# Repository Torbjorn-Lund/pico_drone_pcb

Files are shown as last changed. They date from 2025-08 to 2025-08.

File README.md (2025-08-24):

# pico_drone_pcb





Custom PCB for a Raspberry Pi Pico–powered drone.  

This board integrates the core electronics needed to run a quadcopter, with power regulation, sensor connectors, and interfaces for ESCs and other peripherals.

The corresponding code, written in c can be found [here](https://github.com/Torbjorn-Lund/pico_drone_project)

## Features
- Designed for **Raspberry Pi Pico 2**  
- Power regulation:
  - Buck converter supporting up to **18 V input**
  - **TVS diode protection** limiting input voltage to ~10 V  
  - Optimized for **2S LiPo batteries (≈7.4 V nominal, 8.4 V fully charged)**  
- Breakouts for:
  - ESCs (dshot)
  - IMU (ICM-20948)  
  - Barometer (BMP280)  
  - GPS (NEO-M8N)  
  - Time-of-flight sensor (VL53L1X)  

## Images
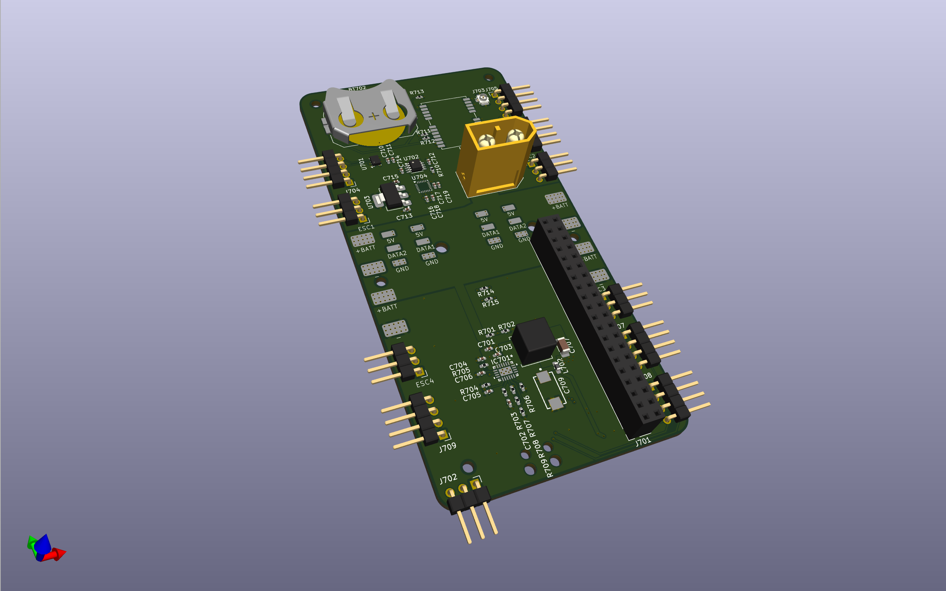
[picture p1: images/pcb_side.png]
PCB image Optional Title

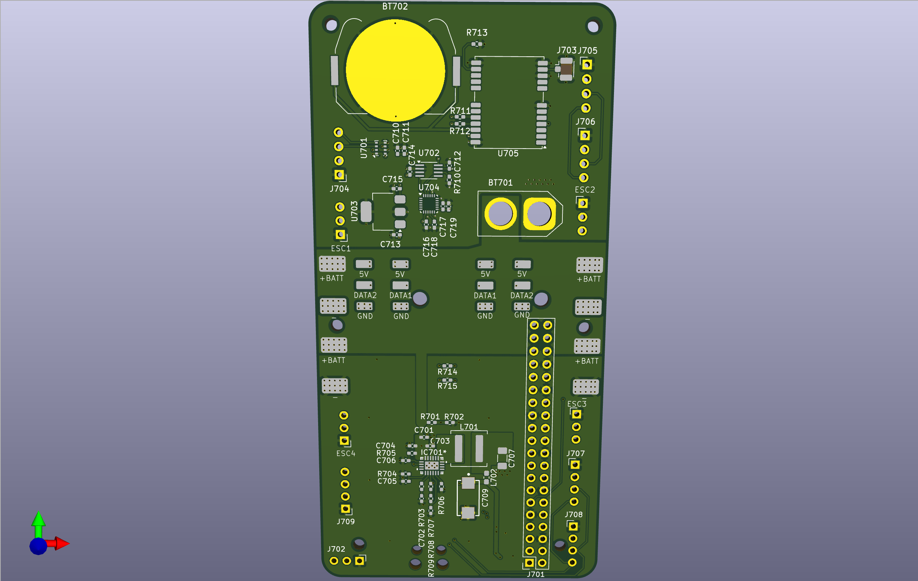
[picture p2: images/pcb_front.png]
PCB image Optional Title

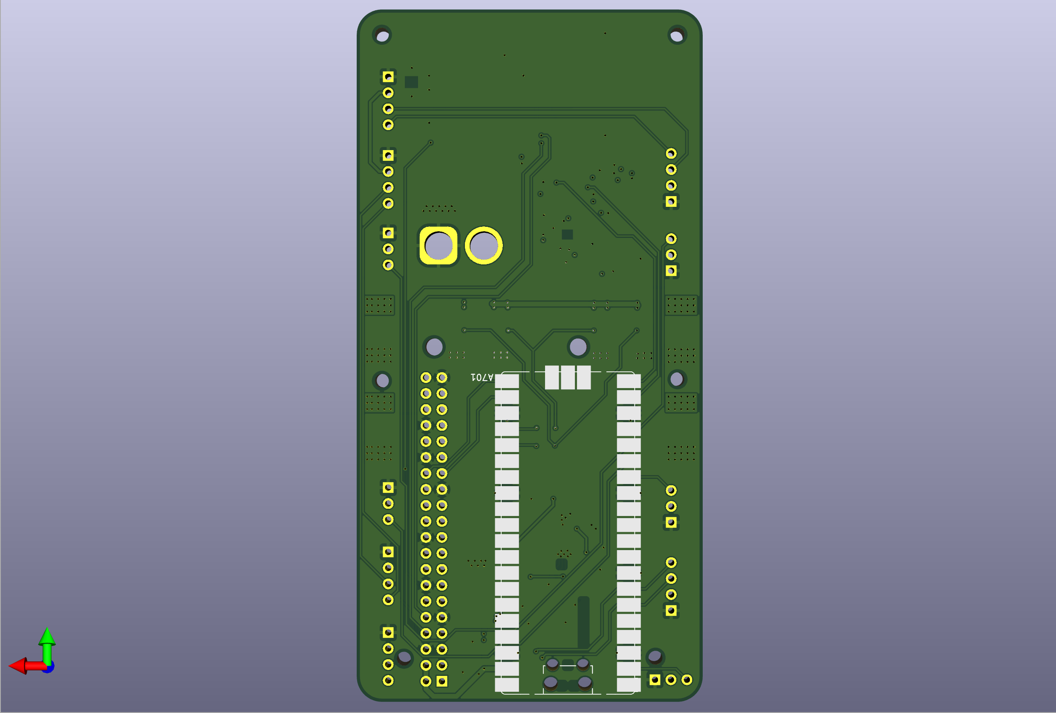
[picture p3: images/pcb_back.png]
PCB image Optional Title


## Notes / Limitations
- TVS diode limits voltage, so this board is not suitable for 3S+ LiPo packs.  
- Board is still under development.

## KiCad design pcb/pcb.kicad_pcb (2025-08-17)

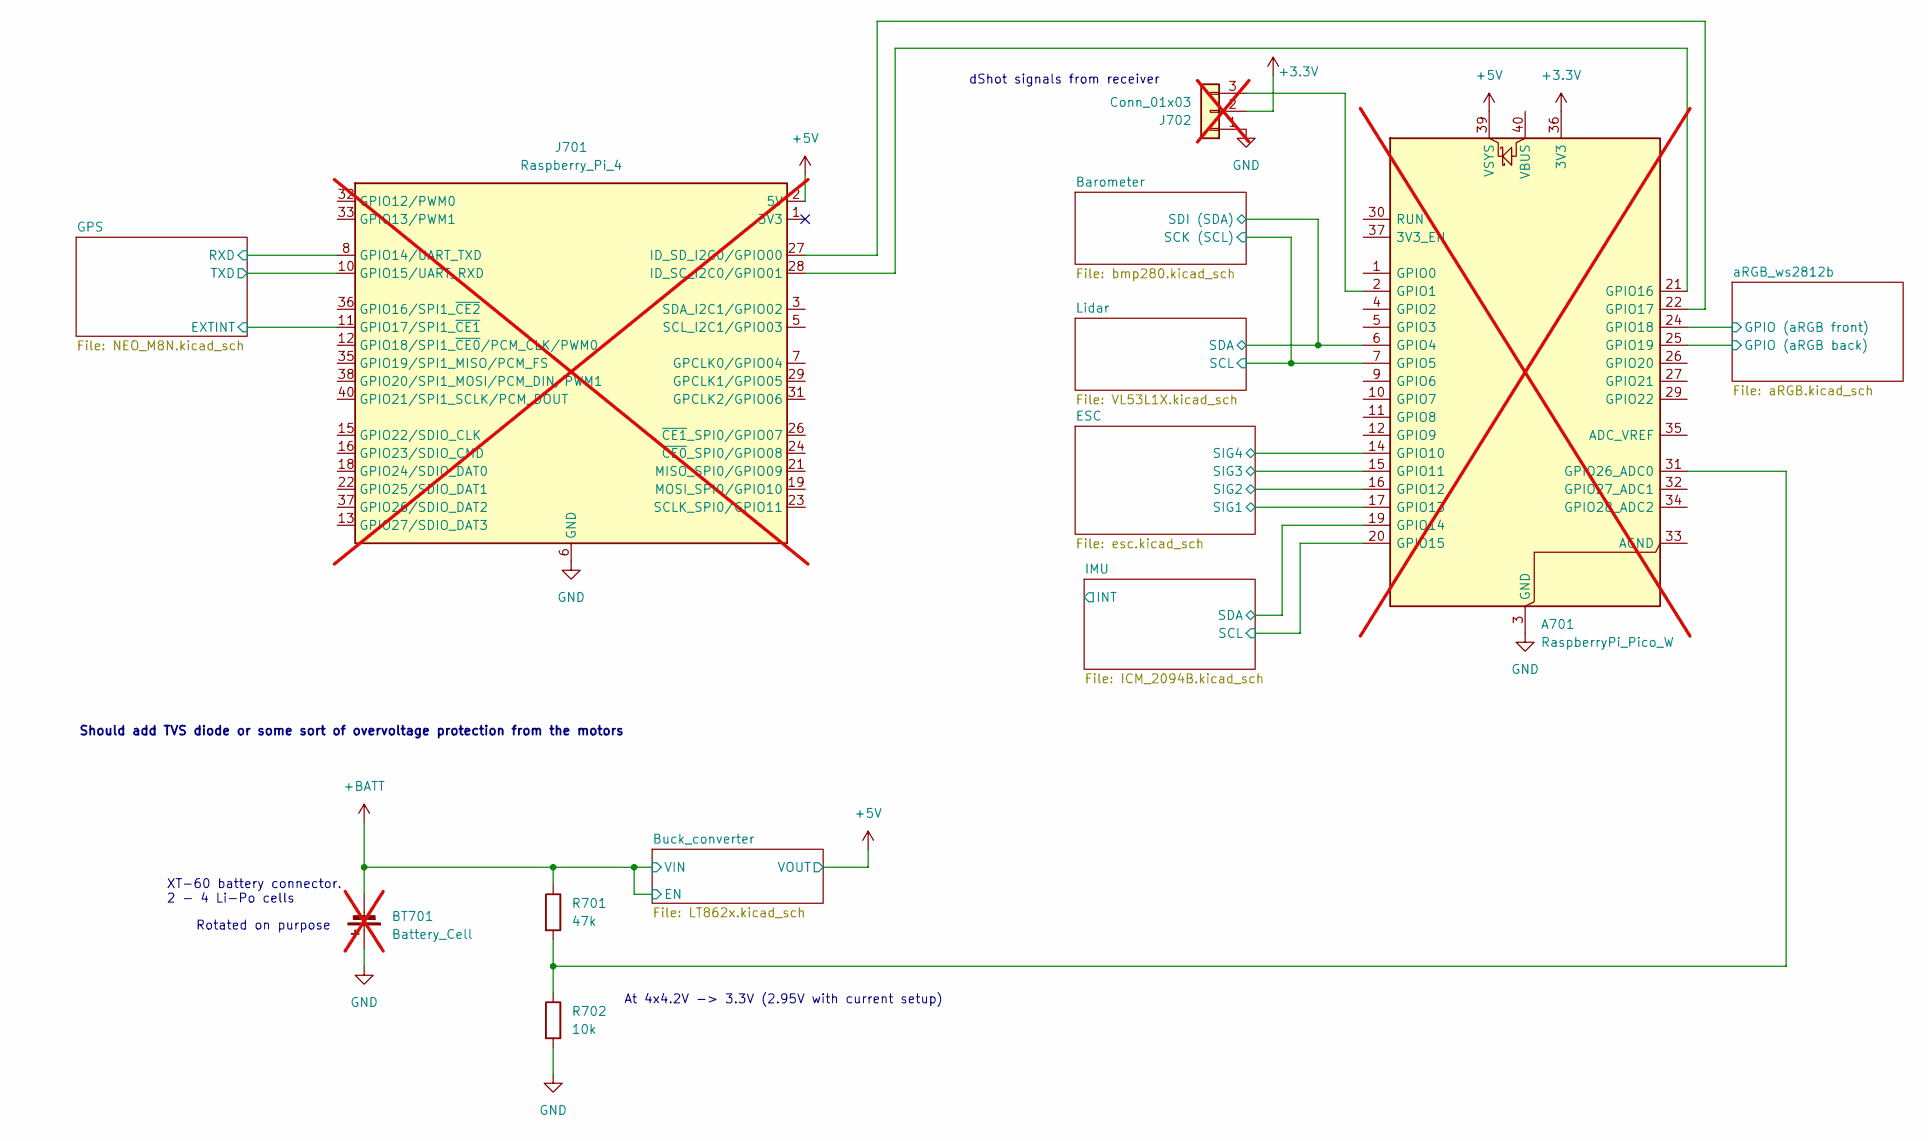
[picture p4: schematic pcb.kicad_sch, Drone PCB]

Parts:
A701: RaspberryPi_Pico_W; RaspberryPi_Pico_SMD_HandSolder; DigiKey 0; not fitted
BT701: Battery_Cell; AMASS_XT60-M_1x02_P7.20mm_Vertical; DigiKey 1738-1437-ND; not fitted
J701: Raspberry_Pi_4; PinSocket_2x20_P2.54mm_Vertical; not fitted
J702: Conn_01x03; PinHeader_1x03_P2.54mm_Horizontal; not fitted
R701: 47k; R_0402_1005Metric_Pad0.72x0.64mm_HandSolder
R702: 10k; R_0402_1005Metric_Pad0.72x0.64mm_HandSolder

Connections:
+3.3V: A701.36 (3V3), J702.2; also elsewhere on the board
+5V: A701.39 (VSYS), J701.2 (5V), J701.4 (5V); also elsewhere on the board
+BATT: BT701.2 (-), R701.1; also elsewhere on the board
/Barometer/SCK (SCL): A701.7 (GPIO5); also elsewhere on the board
/Barometer/SDI (SDA): A701.6 (GPIO4); also elsewhere on the board
/ESC/SIG1: A701.17 (GPIO13); also elsewhere on the board
/ESC/SIG2: A701.16 (GPIO12); also elsewhere on the board
/ESC/SIG3: A701.15 (GPIO11); also elsewhere on the board
/ESC/SIG4: A701.14 (GPIO10); also elsewhere on the board
/GPS/EXTINT: J701.11 (GPIO17/SPI1_~CE1); also elsewhere on the board
/GPS/RXD: J701.8 (GPIO14/UART_TXD); also elsewhere on the board
/GPS/TXD: J701.10 (GPIO15/UART_RXD); also elsewhere on the board
/IMU/SCL: A701.20 (GPIO15); also elsewhere on the board
/IMU/SDA: A701.19 (GPIO14); also elsewhere on the board
/aRGB_ws2812b/GPIO (aRGB back): A701.25 (GPIO19); also elsewhere on the board
/aRGB_ws2812b/GPIO (aRGB front): A701.24 (GPIO18); also elsewhere on the board
GND: A701.3 (GND), A701.8 (GND), A701.13 (GND), A701.18 (GND), A701.23 (GND), A701.28 (GND), A701.38 (GND), BT701.1 (+), J701.6 (GND), J701.9 (GND), J701.14 (GND), J701.20 (GND), J701.25 (GND), J701.30 (GND), J701.34 (GND), J701.39 (GND), J702.1, R702.2; also elsewhere on the board
unnamed: A701.2 (GPIO1), J702.3
unnamed: A701.21 (GPIO16), J701.28 (ID_SC_I2C0/GPIO01)
unnamed: A701.22 (GPIO17), J701.27 (ID_SD_I2C0/GPIO00)
unnamed: A701.31 (GPIO26_ADC0), R701.2, R702.1

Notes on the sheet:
At 4x4.2V -> 3.3V (2.95V with current setup)
Rotated on purpose
dShot signals from receiver
XT-60 battery connector. 2 - 4 Li-Po cells
Should add TVS diode or some sort of overvoltage protection from the motors

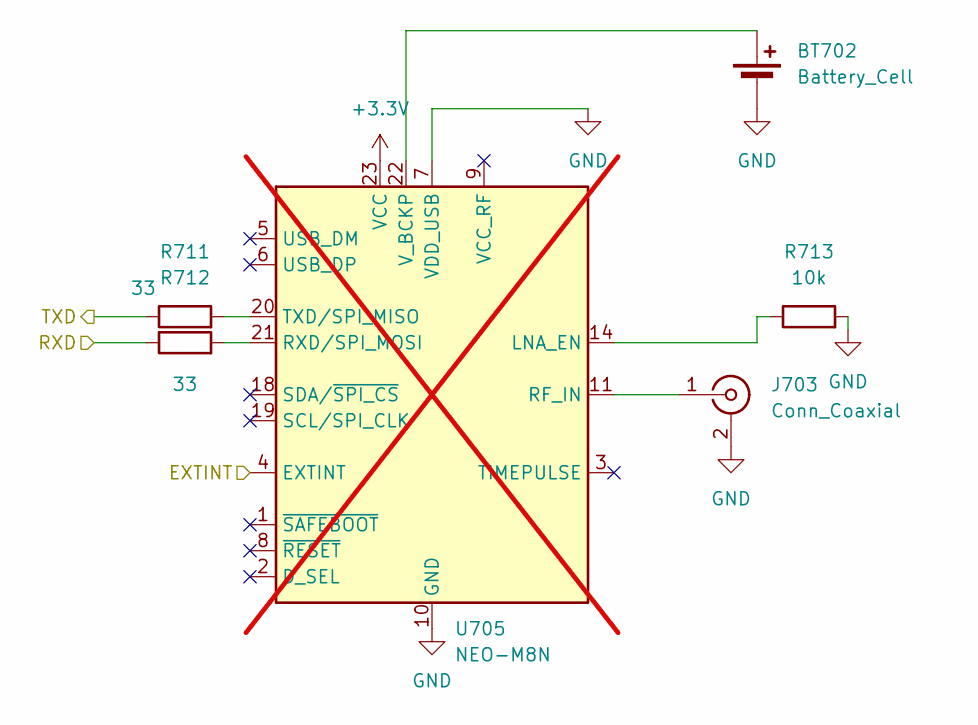
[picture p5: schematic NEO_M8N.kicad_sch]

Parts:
BT702: Battery_Cell; BatteryHolder_Keystone_3034_1x20mm; DigiKey 36-3034-ND
J703: Conn_Coaxial; U.FL_Hirose_U.FL-R-SMT-1_Vertical; DigiKey 26-U.FL-R-SMT-1(60)CT-ND
R711, R712: 33; R_0402_1005Metric_Pad0.72x0.64mm_HandSolder
R713: 10k; R_0402_1005Metric_Pad0.72x0.64mm_HandSolder
U705: NEO-M8N; ublox_NEO; DigiKey 672-NEO-M8N-0CT-ND; not fitted

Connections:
+3.3V: U705.23 (VCC); also elsewhere on the board
/GPS/EXTINT: U705.4 (EXTINT); also elsewhere on the board
/GPS/RXD: R712.1; also elsewhere on the board
/GPS/TXD: R711.1; also elsewhere on the board
GND: BT702.2 (-), J703.2 (Ext), R713.2, U705.7 (VDD_USB), U705.10 (GND), U705.12 (GND), U705.13 (GND), U705.24 (GND); also elsewhere on the board
unnamed: BT702.1 (+), U705.22 (V_BCKP)
unnamed: J703.1 (In), U705.11 (RF_IN)
unnamed: R713.1, U705.14 (LNA_EN)
unnamed: R712.2, U705.21 (RXD/SPI_MOSI)
unnamed: R711.2, U705.20 (TXD/SPI_MISO)

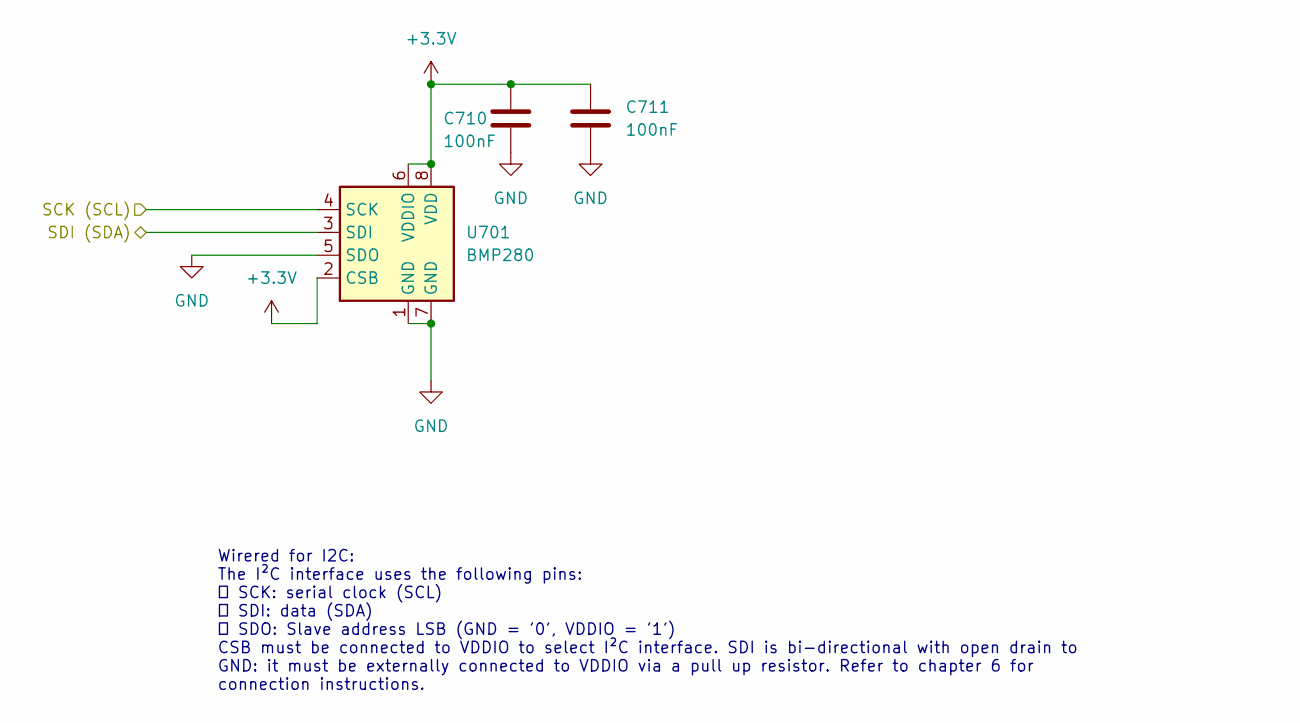
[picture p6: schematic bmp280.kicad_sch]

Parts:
C710, C711: 100nF; C_0402_1005Metric_Pad0.74x0.62mm_HandSolder
U701: BMP280; Bosch_LGA-8_2x2.5mm_P0.65mm_ClockwisePinNumbering; DigiKey 828-1064-2-ND

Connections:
+3.3V: C710.1, C711.1, U701.2 (CSB), U701.6 (VDDIO), U701.8 (VDD); also elsewhere on the board
/Barometer/SCK (SCL): U701.4 (SCK); also elsewhere on the board
/Barometer/SDI (SDA): U701.3 (SDI); also elsewhere on the board
GND: C710.2, C711.2, U701.1 (GND), U701.5 (SDO), U701.7 (GND); also elsewhere on the board

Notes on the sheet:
Wirered for I2C: The I²C interface uses the following pins:  SCK: serial clock (SCL)  SDI: data (SDA)  SDO: Slave address LSB (GND = '0', VDDIO = '1') CSB must be connected to VDDIO to select I²C interface. SDI is bi-directional with open drain to GND: it must be externally connected to VDDIO vi…

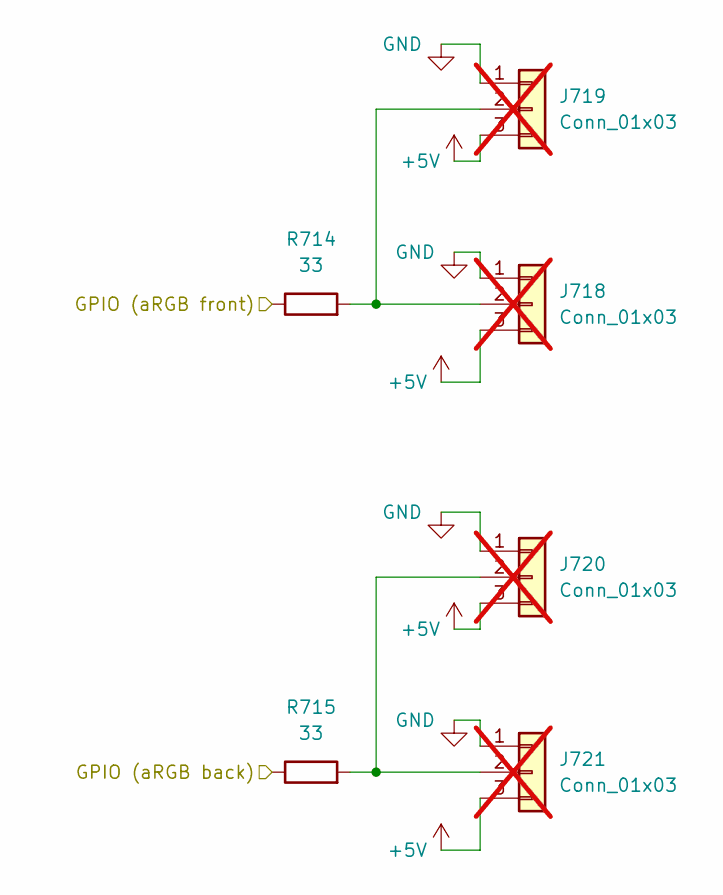
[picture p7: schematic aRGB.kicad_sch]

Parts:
J718, J719, J720, J721: Conn_01x03; aRGB_LED_PAD_CONN; not fitted
R714, R715: 33; R_0402_1005Metric_Pad0.72x0.64mm_HandSolder

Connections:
+5V: J718.3, J719.3, J720.3, J721.3; also elsewhere on the board
/aRGB_ws2812b/GPIO (aRGB back): R715.1; also elsewhere on the board
/aRGB_ws2812b/GPIO (aRGB front): R714.1; also elsewhere on the board
GND: J718.1, J719.1, J720.1, J721.1; also elsewhere on the board
unnamed: J718.2, J719.2, R714.2
unnamed: J720.2, J721.2, R715.2

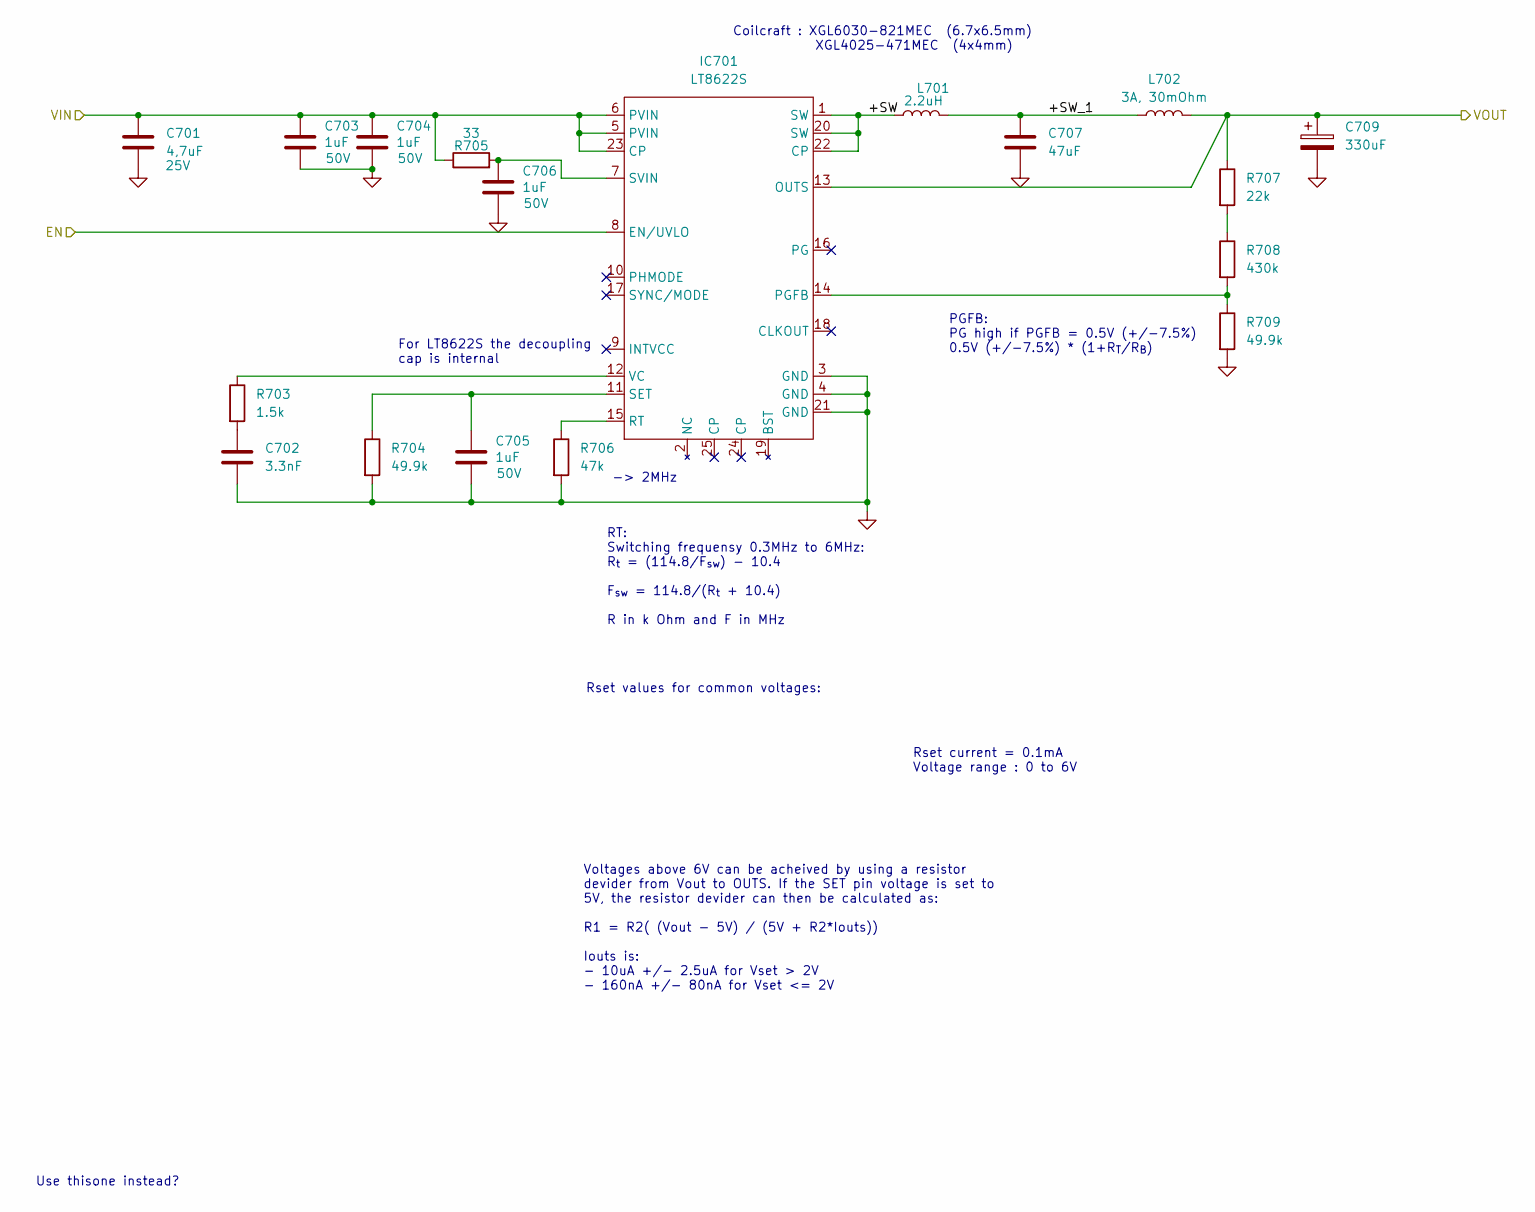
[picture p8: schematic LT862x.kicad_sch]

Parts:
C701: 4,7uF; C_0402_1005Metric_Pad0.74x0.62mm_HandSolder; Voltage 25V; DigiKey 490-GRM155C61E475ME15DCT-ND
C702: 3.3nF; C_0402_1005Metric_Pad0.74x0.62mm_HandSolder
C703, C704, C705, C706: 1uF; C_0402_1005Metric_Pad0.74x0.62mm_HandSolder; Voltage 50V; DigiKey 490-GRM155R61H105KE05DCT-ND
C707: 47uF; C_1206_3216Metric_Pad1.33x1.80mm_HandSolder; DigiKey 445-8047-1-ND
C709: 330uF; CAPMP7343X430N
IC701: LT8622S; QFN-20; DigiKey 505-LT8622SAV#PBF-ND
L701: 2.2uH; L_Coilcraft_XAL6060-XXX; DigiKey 4044-CSEG0660-2R2MCT-ND
L702: 3A, 30mOhm; L_0603_1608Metric_Pad1.05x0.95mm_HandSolder; DigiKey 490-5254-1-ND
R703: 1.5k; R_0402_1005Metric_Pad0.72x0.64mm_HandSolder
R704, R709: 49.9k; R_0402_1005Metric_Pad0.72x0.64mm_HandSolder
R705: 33; R_0402_1005Metric_Pad0.72x0.64mm_HandSolder
R706: 47k; R_0402_1005Metric_Pad0.72x0.64mm_HandSolder
R707: 22k; R_0402_1005Metric_Pad0.72x0.64mm_HandSolder
R708: 430k; R_0402_1005Metric_Pad0.72x0.64mm_HandSolder

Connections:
+5V: C709.1, IC701.13 (OUTS), L702.2, R707.1; also elsewhere on the board
+BATT: C701.1, C703.1, C704.1, IC701.5 (PVIN), IC701.6 (PVIN), IC701.8 (EN/UVLO), IC701.23 (CP), R705.1; also elsewhere on the board
/Buck_converter/+SW: IC701.1 (SW), IC701.20 (SW), IC701.22 (CP), L701.1
/Buck_converter/+SW_1: C707.1, L701.2, L702.1
GND: C701.2, C702.2, C703.2, C704.2, C705.2, C706.2, C707.2, C709.2, IC701.3 (GND), IC701.4 (GND), IC701.21 (GND), R704.2, R706.2, R709.2; also elsewhere on the board
unnamed: C702.1, R703.2
unnamed: IC701.14 (PGFB), R708.2, R709.1
unnamed: IC701.15 (RT), R706.1
unnamed: C705.1, IC701.11 (SET), R704.1
unnamed: C706.1, IC701.7 (SVIN), R705.2
unnamed: IC701.12 (VC), R703.1
unnamed: R707.2, R708.1

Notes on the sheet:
-> 2MHz
Rset current = 0.1mA Voltage range : 0 to 6V
PGFB: PG high if PGFB = 0.5V (+/-7.5%) 0.5V (+/-7.5%) * (1+R_{T}/R_{B})
For LT8622S the decoupling cap is internal
Voltages above 6V can be acheived by using a resistor devider from Vout to OUTS. If the SET pin voltage is set to 5V, the resistor devider can then be calculated as: R1 = R2( (Vout - 5V) / (5V + R2*Iouts)) Iouts is: - 10uA +/- 2.5uA for Vset > 2V - 160nA +/- 80nA for Vset <= 2V
Rset values for common voltages:
RT: Switching frequensy 0.3MHz to 6MHz: R_{t} = (114.8/F_{sw}) - 10.4 F_{sw} = 114.8/(R_{t} + 10.4) R in k Ohm and F in MHz
Use thisone instead?
Coilcraft : XGL6030-821MEC (6.7x6.5mm) XGL4025-471MEC (4x4mm)

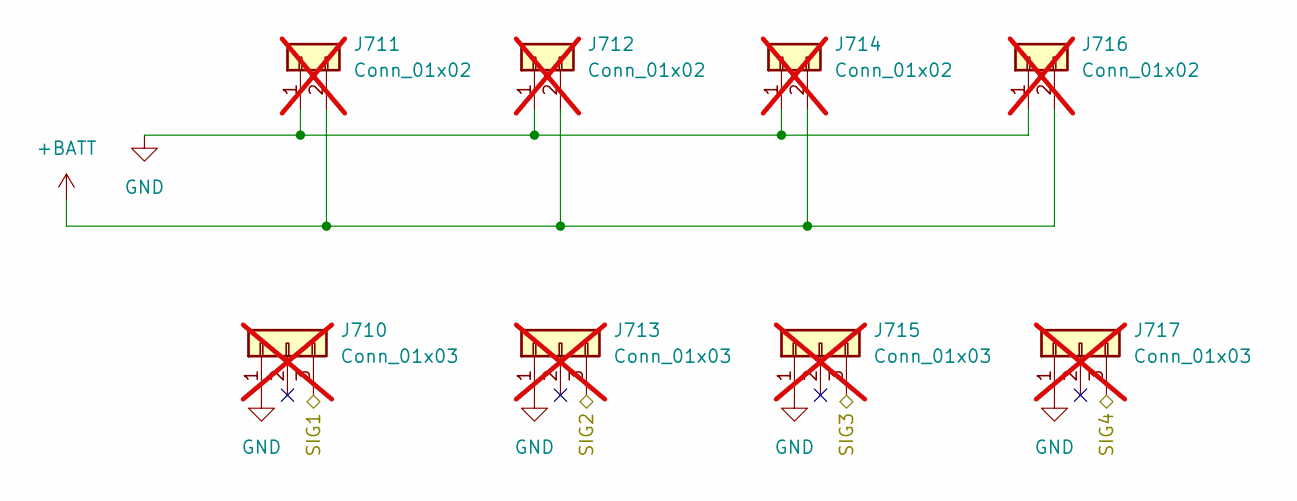
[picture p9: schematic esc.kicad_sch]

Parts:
J710, J713, J715, J717: Conn_01x03; PinHeader_1x03_P2.54mm_Horizontal; not fitted
J711, J712, J714, J716: Conn_01x02; ESC_Power_Pad_01x02; not fitted

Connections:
+BATT: J711.2, J712.2, J714.2, J716.2; also elsewhere on the board
/ESC/SIG1: J710.3; also elsewhere on the board
/ESC/SIG2: J713.3; also elsewhere on the board
/ESC/SIG3: J715.3; also elsewhere on the board
/ESC/SIG4: J717.3; also elsewhere on the board
GND: J710.1, J711.1, J712.1, J713.1, J714.1, J715.1, J716.1, J717.1; also elsewhere on the board

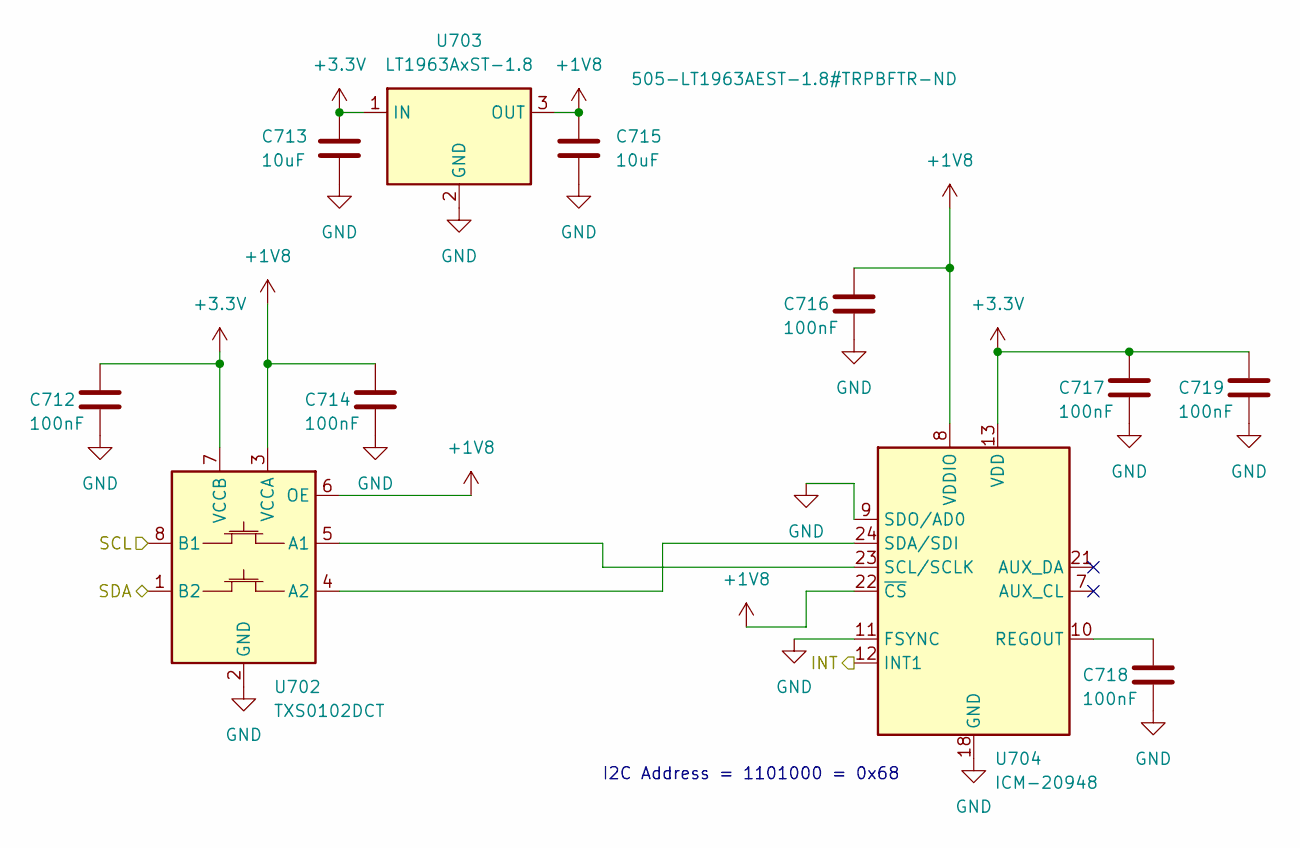
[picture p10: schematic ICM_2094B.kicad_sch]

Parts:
C712, C714, C716, C717, C718, C719: 100nF; C_0402_1005Metric_Pad0.74x0.62mm_HandSolder
C713, C715: 10uF; C_0402_1005Metric_Pad0.74x0.62mm_HandSolder
U702: TXS0102DCT; SSOP-8_2.95x2.8mm_P0.65mm; DigiKey 296-TXS0102DCTRCT-ND
U703: LT1963AxST-1.8; SOT-223-3_TabPin2; DigiKey 505-LT1963AEST-1.8#TRPBFTR-ND
U704: ICM-20948; InvenSense_QFN-24_3x3mm_P0.4mm; DigiKey 1428-1123-1-ND

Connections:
+3.3V: C712.1, C713.1, C717.1, C719.1, U702.7 (VCCB), U703.1 (IN), U704.13 (VDD); also elsewhere on the board
/IMU/INT: U704.12 (INT1)
/IMU/SCL: U702.8 (B1); also elsewhere on the board
/IMU/SDA: U702.1 (B2); also elsewhere on the board
GND: C712.2, C713.2, C714.2, C715.2, C716.2, C717.2, C718.2, C719.2, U702.2 (GND), U703.2 (GND), U704.9 (SDO/AD0), U704.11 (FSYNC), U704.18 (GND), U704.20 (GND); also elsewhere on the board
unnamed: U702.5 (A1), U704.23 (SCL/SCLK)
unnamed: U702.4 (A2), U704.24 (SDA/SDI)
unnamed: C718.1, U704.10 (REGOUT)

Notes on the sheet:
I2C Address = 1101000 = 0x68

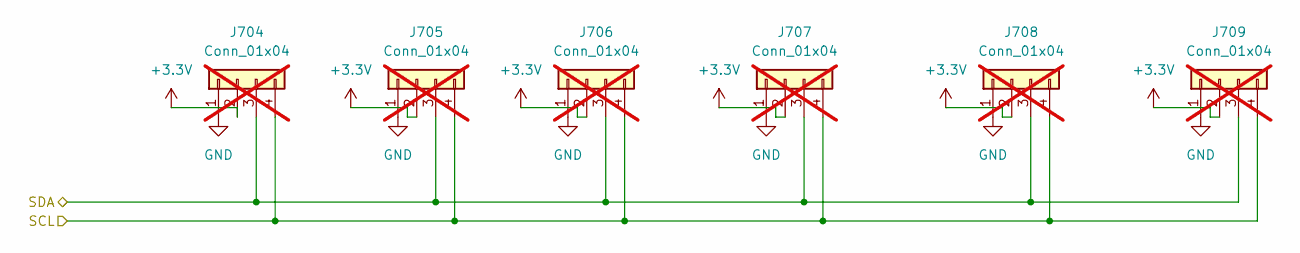
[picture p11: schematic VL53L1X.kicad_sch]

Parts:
J704, J705, J706, J707, J708, J709: Conn_01x04; PinHeader_1x04_P2.54mm_Horizontal; not fitted

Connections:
+3.3V: J704.2, J705.2, J706.2, J707.2, J708.2, J709.2; also elsewhere on the board
/Barometer/SCK (SCL): J704.4, J705.4, J706.4, J707.4, J708.4, J709.4; also elsewhere on the board
/Barometer/SDI (SDA): J704.3, J705.3, J706.3, J707.3, J708.3, J709.3; also elsewhere on the board
GND: J704.1, J705.1, J706.1, J707.1, J708.1, J709.1; also elsewhere on the board

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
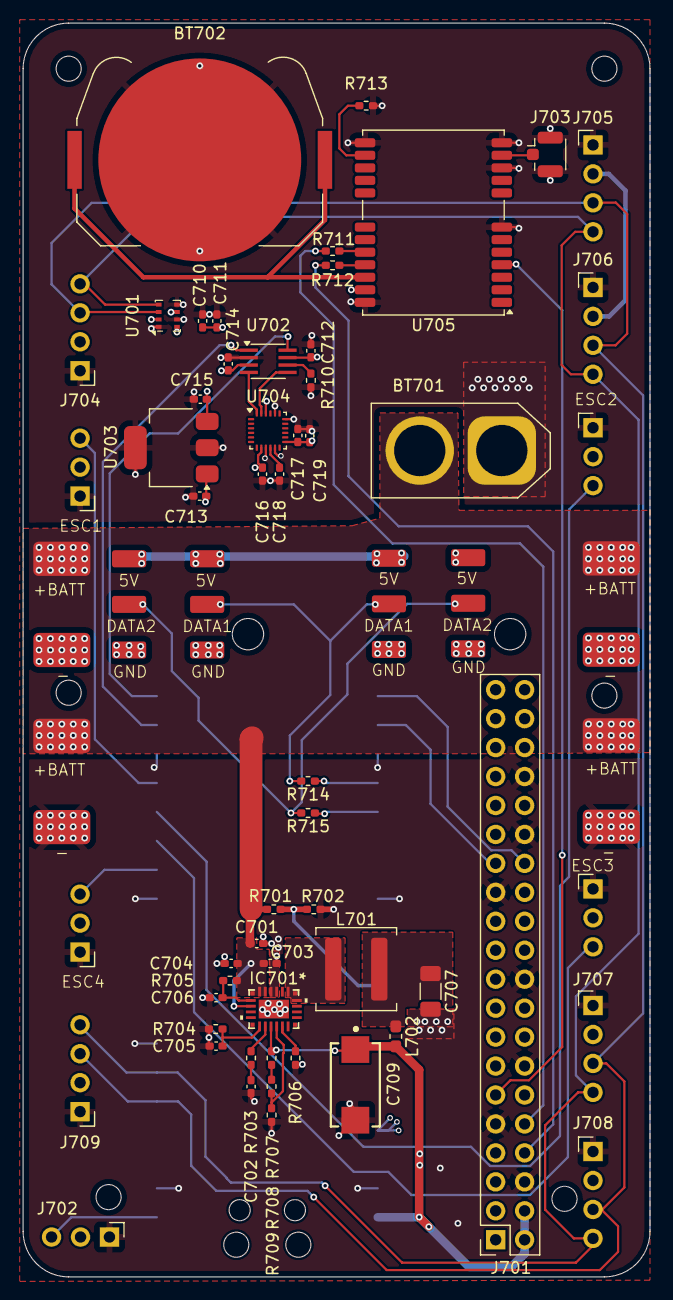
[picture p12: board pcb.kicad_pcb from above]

Board: 4 copper layers, 55.0 x 110.0 mm, 65 parts (1 on the bottom side), 42 nets.

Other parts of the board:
R710: 10k; R_0402_1005Metric_Pad0.72x0.64mm_HandSolder

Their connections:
GND: R710.2; also elsewhere on the board

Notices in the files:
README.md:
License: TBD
